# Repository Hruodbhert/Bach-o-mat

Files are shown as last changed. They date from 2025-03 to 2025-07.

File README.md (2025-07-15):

# Bach-o-mat: Electromechanical MIDI Player for Keyboards

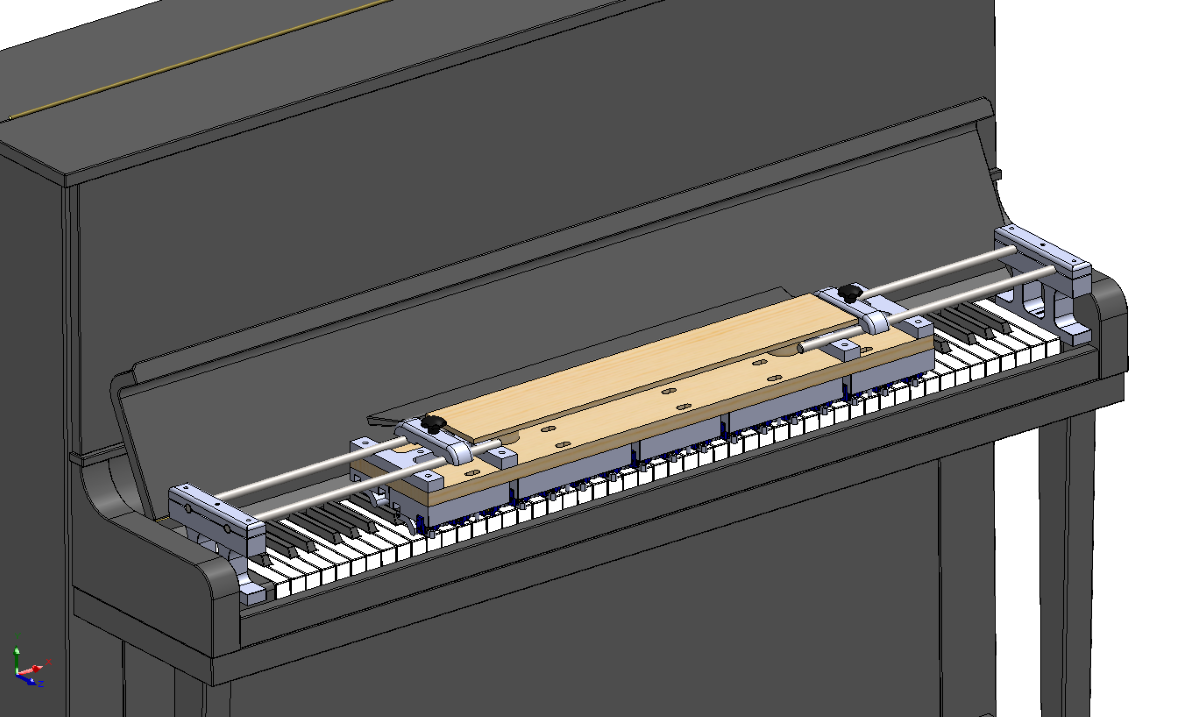
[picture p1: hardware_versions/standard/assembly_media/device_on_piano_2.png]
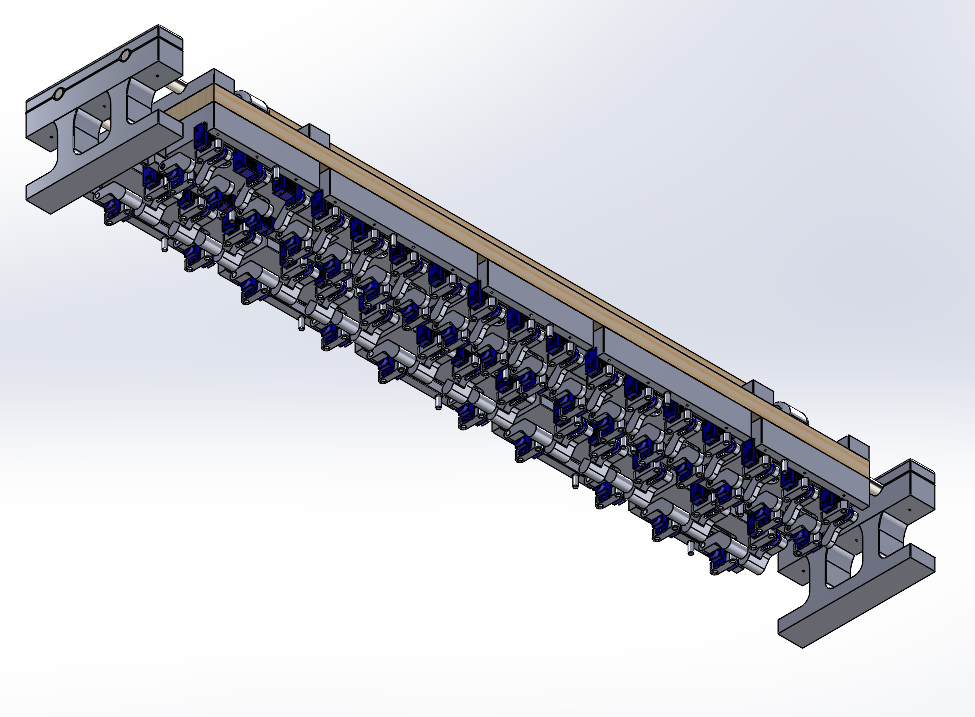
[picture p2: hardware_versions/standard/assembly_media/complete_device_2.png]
|  |  |
| --- | --- |

**Bach-o-mat** is an open-source electromechanical device designed to play **pipe organs**, but it can also be used on any **keyboard instrument**. It operates using **Arduino and micro servomotors**, allowing it to play music by interfacing with a **MIDI control device**.

---

## How It Works
A control device (such as a **PC or smartphone**) connects to Bach-o-mat via **USB** (with **Bluetooth support coming soon**) and sends MIDI signals to activate the keyboard's notes.

## Modular and Expandable Design

Originally developed for **58-note keyboards**, a standard commonly used in **pipe organs until the late 19th century**, Bach-o-mat is built on a **modular architecture**:

- Each **octave of keys** is handled by separate mechanical modules.
- Modules can be easily **combined** and **repositioned** to fit keyboards of different sizes and also with **different key widths**.
- **Sliding side supports** can be employed in order to freely match the layout of any keyboard instrument.

---

## Repository Structure

The repository is organized to support **multiple hardware and electronics versions**.

```
Bach-o-mat/
├── hardware_versions/ # Different 3D and 2D mechanical designs
│ ├── standard/
│ ├── optimized/
│ └── ...
├── electronics_versions/ # Different circuit designs and firmware
│ ├── v1/
│ ├── v2/
│ └── ...
├── docs/ # Shared instructions and documentation
├── README.md # This file
└── LICENSE # Open-source license
```

### `hardware_versions/`

This directory contains **alternative mechanical versions** of Bach-o-mat:

- `standard/`: Original version for 58-note keyboards, with sliding side supports and a horizontal depth of 16 cm
- `optimized/`: 58-notes keyboard version, with fixed supports and an optimized horizontal depth of 11.5 cm

Each subfolder includes:
- **3D models** for 3D printing
- **2D design files** for laser cutting and CNC machining
- Assembly diagrams and media
- A local `README.md` describing that version

### `electronics_versions/`

This directory contains **electronics and firmware variants**, each matching a different design approach:

- `v1/`: Only USB-MIDI interface, with 1 Arduino Micro as master and 5 Arduino Nano as servo controllers
- `v2/`: USB-MIDI and BLE-MIDI interface, with 1 Arduino Nano 33 IoT as master, 1 Arduino Micro for USB-MIDI interface and 5 PCA9685 modules as servo controllers

Each subfolder includes:
- Circuit schematics and wiring diagrams
- Arduino code and configuration files
- Python code of the calibration program
- A local `README.md` with build and upload instructions

---

## Getting Started

1. Browse available versions in [`hardware_versions/`](hardware_versions/) and [`electronics_versions/`](electronics_versions/)
2. Select the combination that fits your needs
3. Follow the `README.md` inside the chosen folders for detailed instructions
4. Assemble, upload firmware, and connect your MIDI control source
5. Enjoy automated keyboard music!

---

## Demonstration

A video demonstration of Bach-o-mat in action is available:

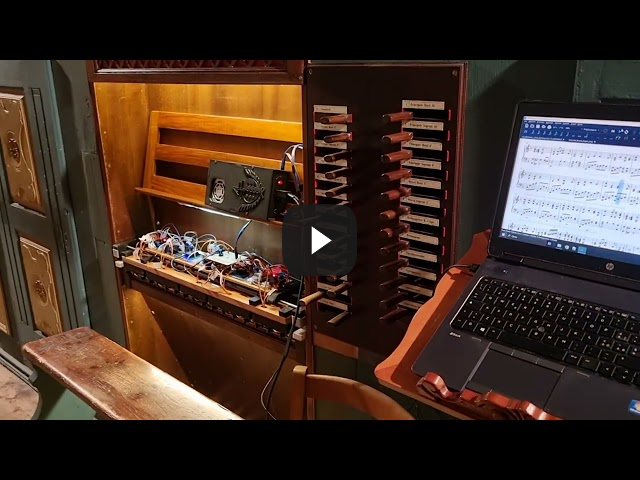
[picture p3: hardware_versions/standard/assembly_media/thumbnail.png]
Setup on Organ Playing (https://youtu.be/sfZ5kHSBi4M?si=CWz8P8_79pBXwW5q)


---

## Future Improvements

- **Expanded keyboard support** for even larger instruments
- **Optimized motor response** for improved playability

---

## License

Bach-o-mat is released under the **GNU General Public License**, making it freely available for modification and use. If you improve the project, consider contributing your modifications back to the community.

---

For any inquiries or contributions, please open an **Issue** or submit a **Pull Request**.

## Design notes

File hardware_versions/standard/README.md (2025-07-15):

# Hardware - Version Standard - 58-Key Modular Design

This is the **original mechanical version** of the Bach-o-mat, designed for **58-key pipe organ-style keyboards**.

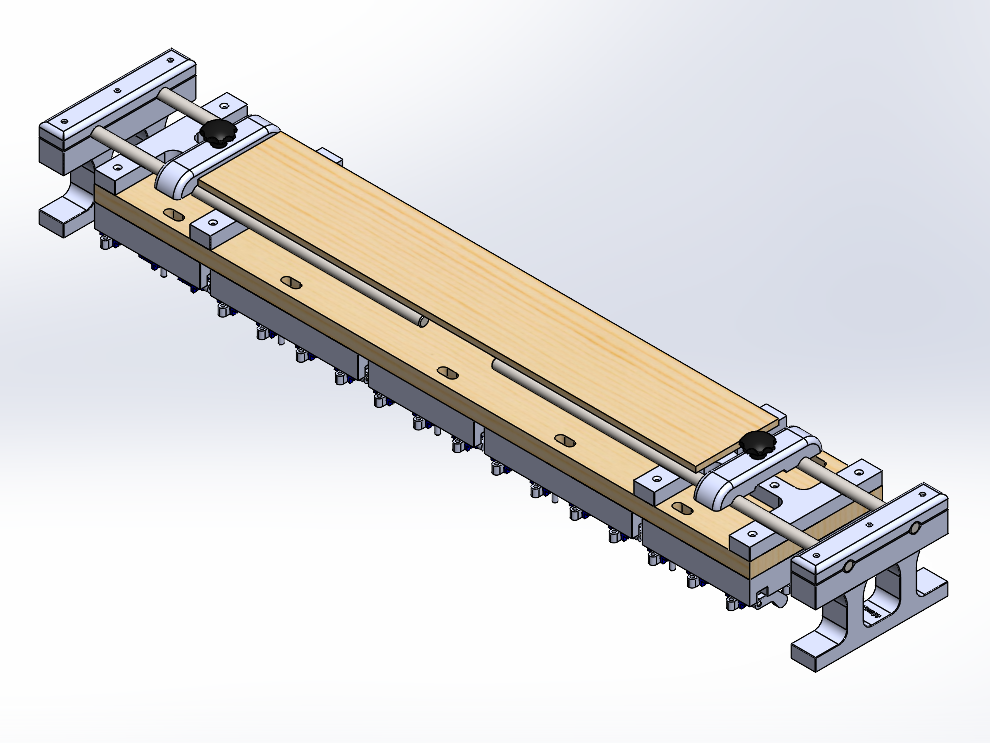
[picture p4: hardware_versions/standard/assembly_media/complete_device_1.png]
 

---

## Table of Contents

1. [Key Features](#key-features)  
2. [Assembly Overview](#assembly-overview)
3. [Compatibility](#compatibility)  
4. [Folder Contents](#folder-contents)
5. [Reference Images](#reference-images)  
6. [License](#license)

---

## Key Features

- Supports **58 keys**
- **Modular structure**: Separate modules for each octave of natural and accidental keys
- **Adjustable horizontal spacing** for compatibility with various key widths from ... mm to ... mm
- **Sliding support bars** for flexible placement across different instruments
- Designed for **FDM 3D printing** and **laser cutting**

---

## Assembly Overview

Each octave consists of:
- A **natural keys module** (white keys)
- An **accidental keys module** (black keys)

For both natural keys and accidental keys modules there is a shorter model for the last octave which has only 10 notes.

These modules can be **replicated and aligned** to form the full 58-key span.

The device rests on two **side support bars**, which:
- Slide to match the keyboard width
- Allow for **non-invasive mounting** (no screws or adhesives required)

The servos are housed in a base layer and press the keys from above using improved 3D printed mechanical arms.

Here below you can find some exploded views for a better understanding of the assembly process.

| Description | Picture |
|---|---|
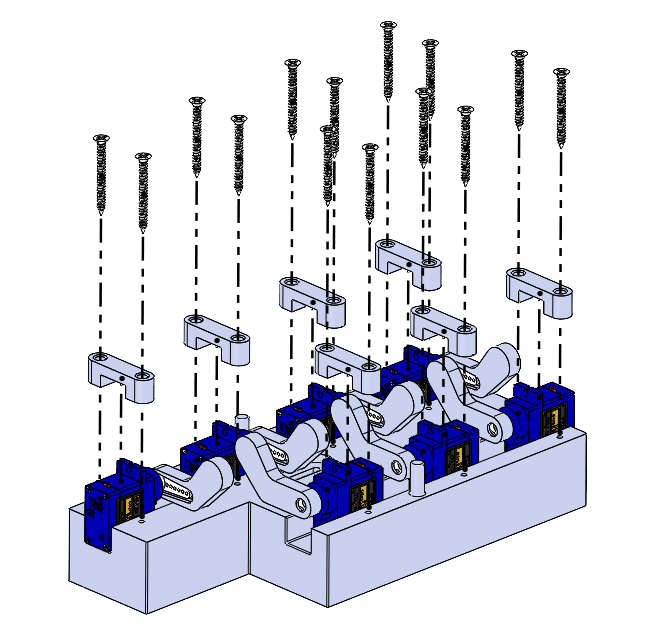
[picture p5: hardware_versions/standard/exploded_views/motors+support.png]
|Motors on the support  ||
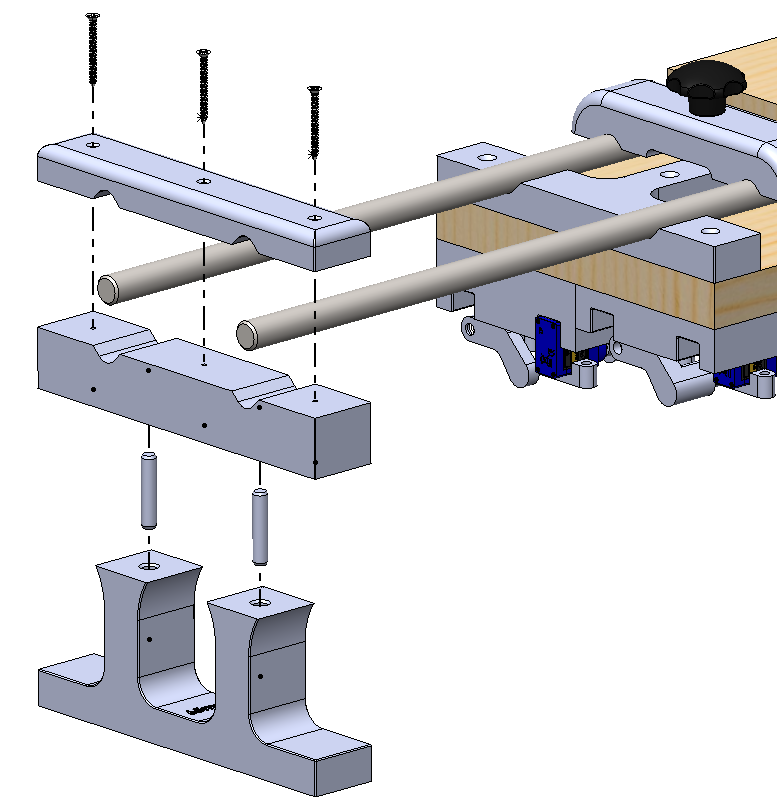
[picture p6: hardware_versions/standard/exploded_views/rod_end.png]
|Rod end ||
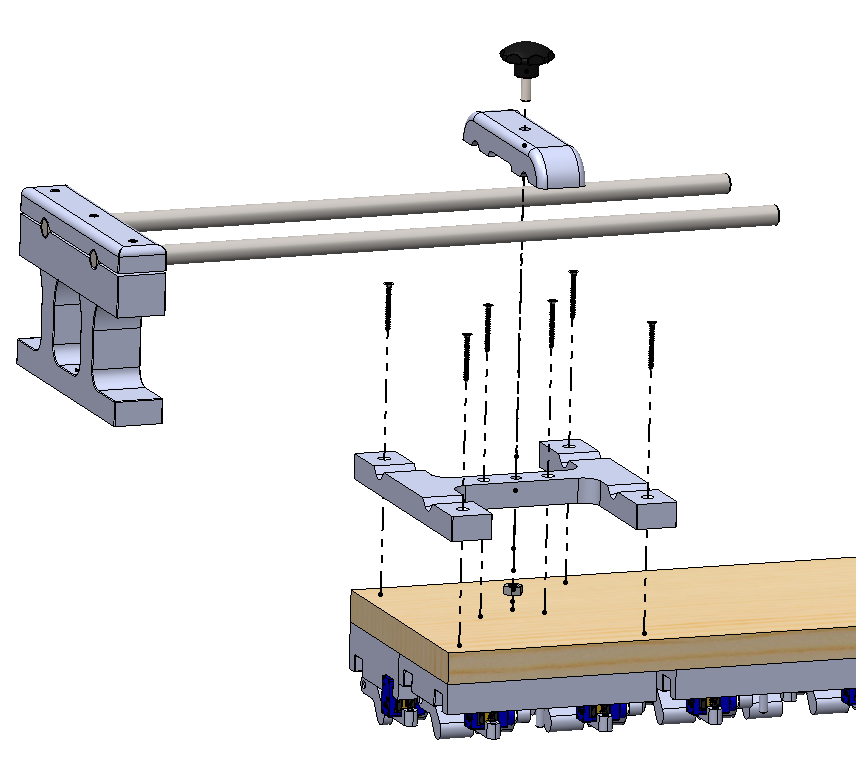
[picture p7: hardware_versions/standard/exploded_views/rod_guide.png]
|Rod guide ||
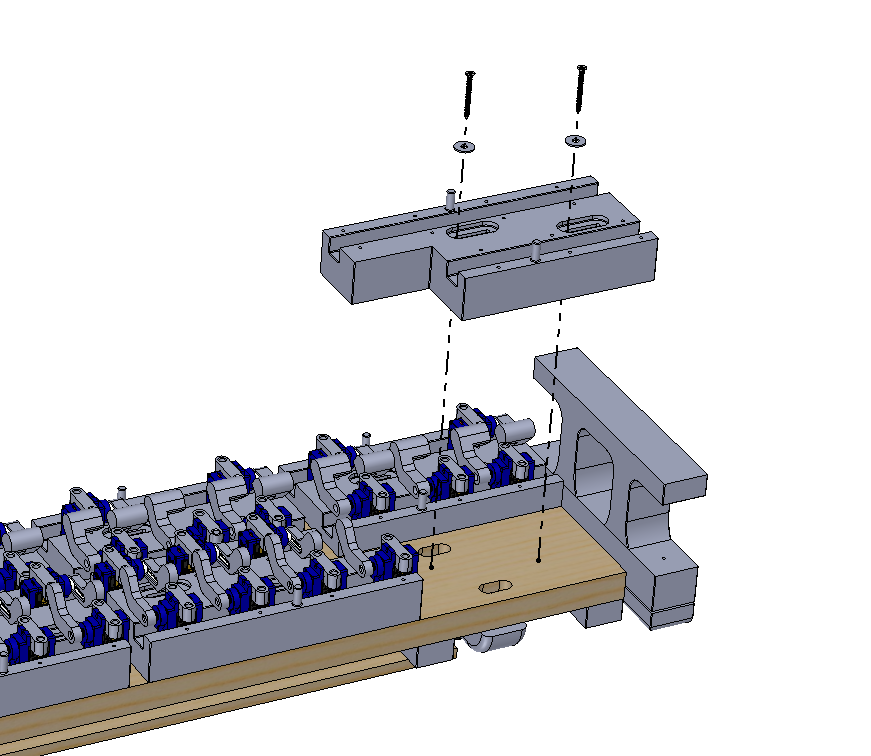
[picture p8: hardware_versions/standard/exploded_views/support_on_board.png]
|Support on board ||

---

## Compatibility

Thanks to the adaptibility of its supports this version is intended for being carried in different places and used to play a wide range of disparate keyboard instruments.<br>
The 3D printable modules are designed to be compatible with almost any keyboard, both historical and commercial, leaving just the duty to pay attention to where to screw them. They should also fit well with quite any commercial microservo available nowadays.<br>
The only non-standard components are the arms of the servos, which may change quite a lot among different models and brands. The 3D printable files provided have therefore a proper external shape, but it might be necessary to change the socket for the servo arm.

---

## Folder Contents

```
standard/
├── 3D_models/ # STEP files for all printed parts
├── 2D_designs/ # DXF files for laser-cut components
├── assembly_media/ # Images and diagrams
├── exploded_views/ # Assembly 3D schemes
└── README.md # This file
```

---

## Reference Images

| Description | Picture |
|---|---|
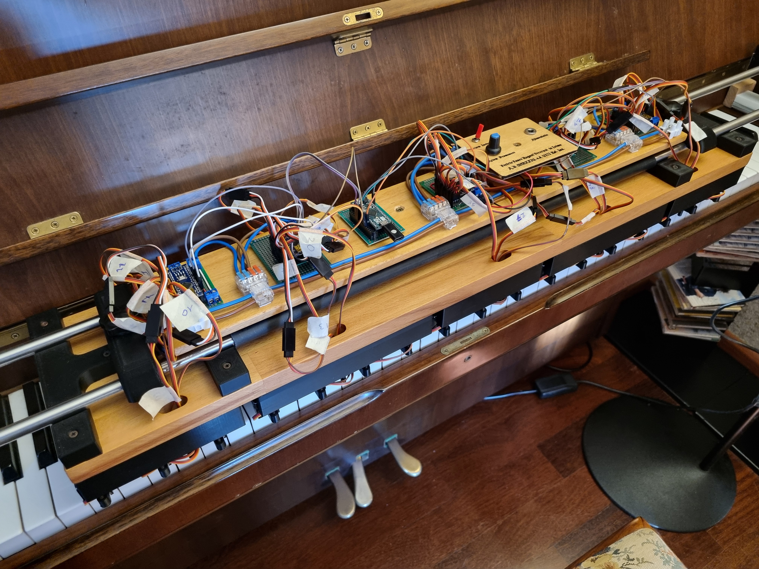
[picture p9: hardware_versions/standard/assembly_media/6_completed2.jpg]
| Assembled Device on Piano  |  |
| Assembled Device on Organ  |  |
| Full Module View |  |

---

## License

Bach-o-mat is released under the **GNU General Public License**, making it freely available for modification and use. If you improve the project, consider contributing your modifications back to the community.

---

For full documentation and software, return to the [main README](../../README.md).

For any inquiries or contributions, please open an **Issue** or submit a **Pull Request**.

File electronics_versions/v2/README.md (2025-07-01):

# Electronics - Version 2 - MIDI-USB and MIDI-BLE

This is an improved version of Bach-o-mat's electronics and firmware,
which allows a **BLE-MIDI connection** to the automaton and adds a **display** and an **encoder** for an easier and PC-less calibration procedure.

# Coming soon!
We are testing it right now, it will be uploaded as soon as possible.

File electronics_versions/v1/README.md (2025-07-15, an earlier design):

# Electronics - Version 1 - MIDI-USB device

This is the first developed version of Bach-o-mat's electronics and firmware, which allows a USB-MIDI connection to the automaton and performs the calibration procedure through a PC.

In terms of microcontrolers here we use

- **Master**: 1x Arduino Micro, which receives MIDI events over USB and routes them to the Nano boards.  
- **Slaves**: 5× Arduino Nano, each controlling 12 servos (one octave of notes).

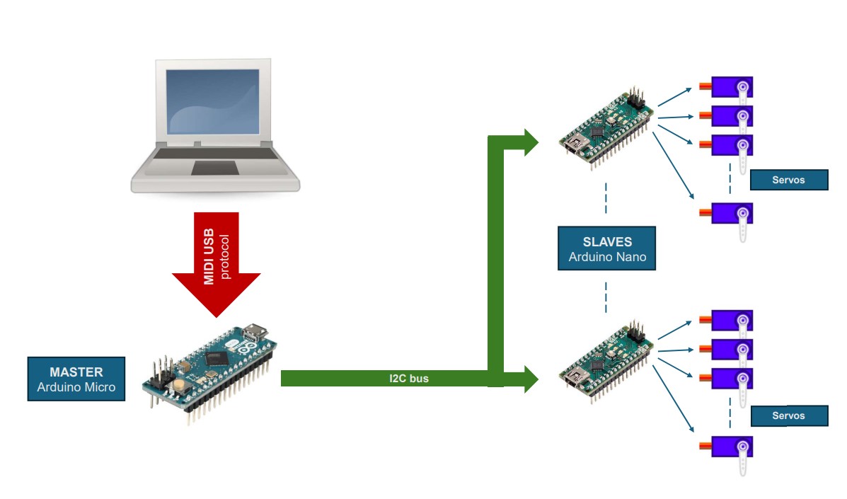
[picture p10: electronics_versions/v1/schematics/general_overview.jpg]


---

## Table of Contents

1. [Hardware Requirements](#hardware-requirements)  
2. [Schematic & Wiring](#schematic--wiring)  
3. [Software Requirements](#software-requirements)  
4. [Usage](#usage)  
5. [Calibration Mode](#calibration-mode)  
6. [Folder Contents](#folder-contents)
7. [License](#license)  

---

## Hardware Requirements

- 1× **Arduino Micro**  
- 5× **Arduino Nano**  
- 60× servos (12 per Nano)  
- Common I²C bus (SDA/SCL) wiring  
- 5 V power supply capable of driving all servos  
- Push-button or switch to Arduino Micro pin 8 (calibration/play mode)  
- Wires, resistors, prototyping board or custom PCB  

---

## Schematic & Wiring

1. **Arduino Micro**  
   - Pin 8 → calibration mode switch  
   - Built‐in LED → mode indicator
   - USB → PC MIDI‐USB
   - SDA, SCL → shared I²C bus to all Nanos

2. **Each Arduino Nano**  
   - A0 (analog) → calibration mode detect  
   - Digital pins 2…13 → servo signal lines (one per note, in total 12 servos (one octave of notes) per Nano)  
   - SDA, SCL → shared I²C bus  
   - 5 V and GND → common power rails  

> **Note:** Assign each Nano a distinct I²C address equal to `OFFSET_INDIRIZZI + INDIRIZZO_MANO`, where `INDIRIZZO_MANO` = 0…4.

Here below you can see the wiring diagram of each Arduino Nano.

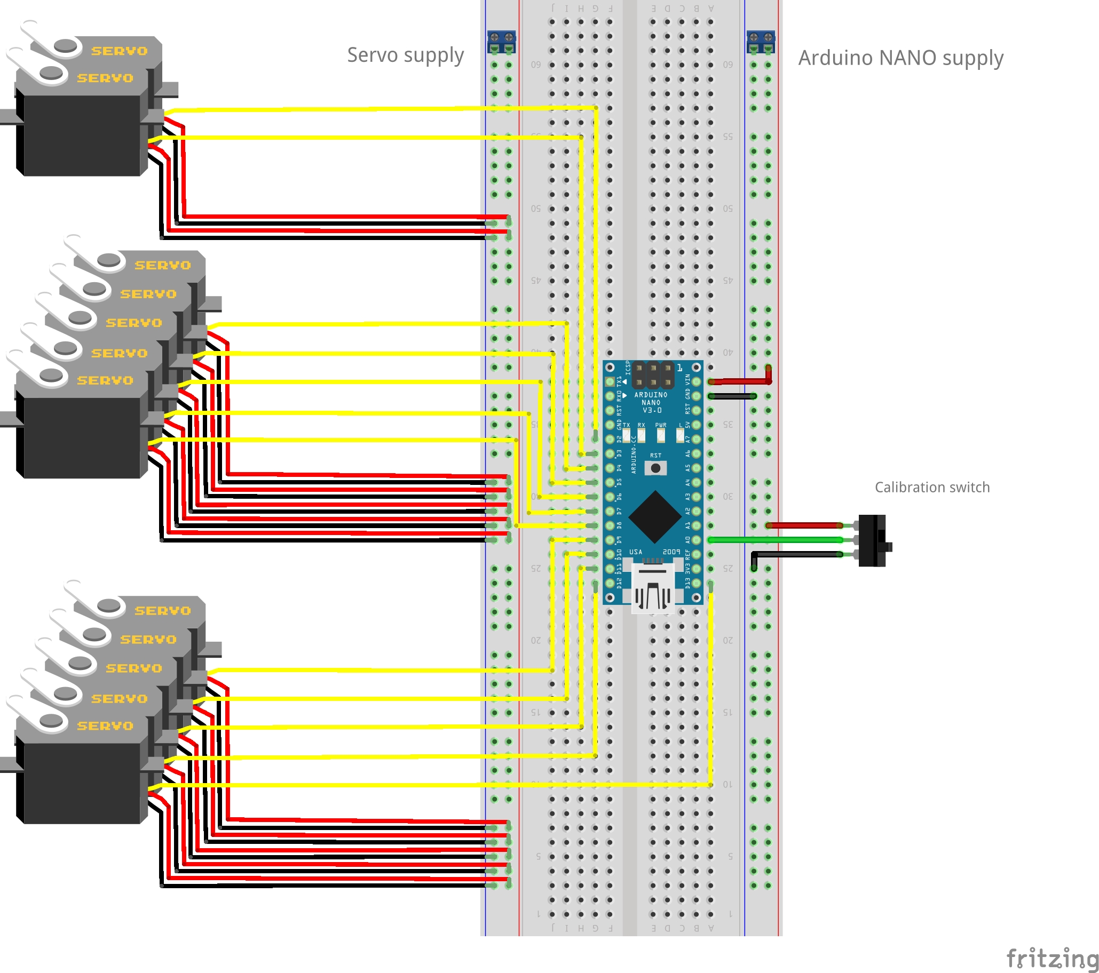
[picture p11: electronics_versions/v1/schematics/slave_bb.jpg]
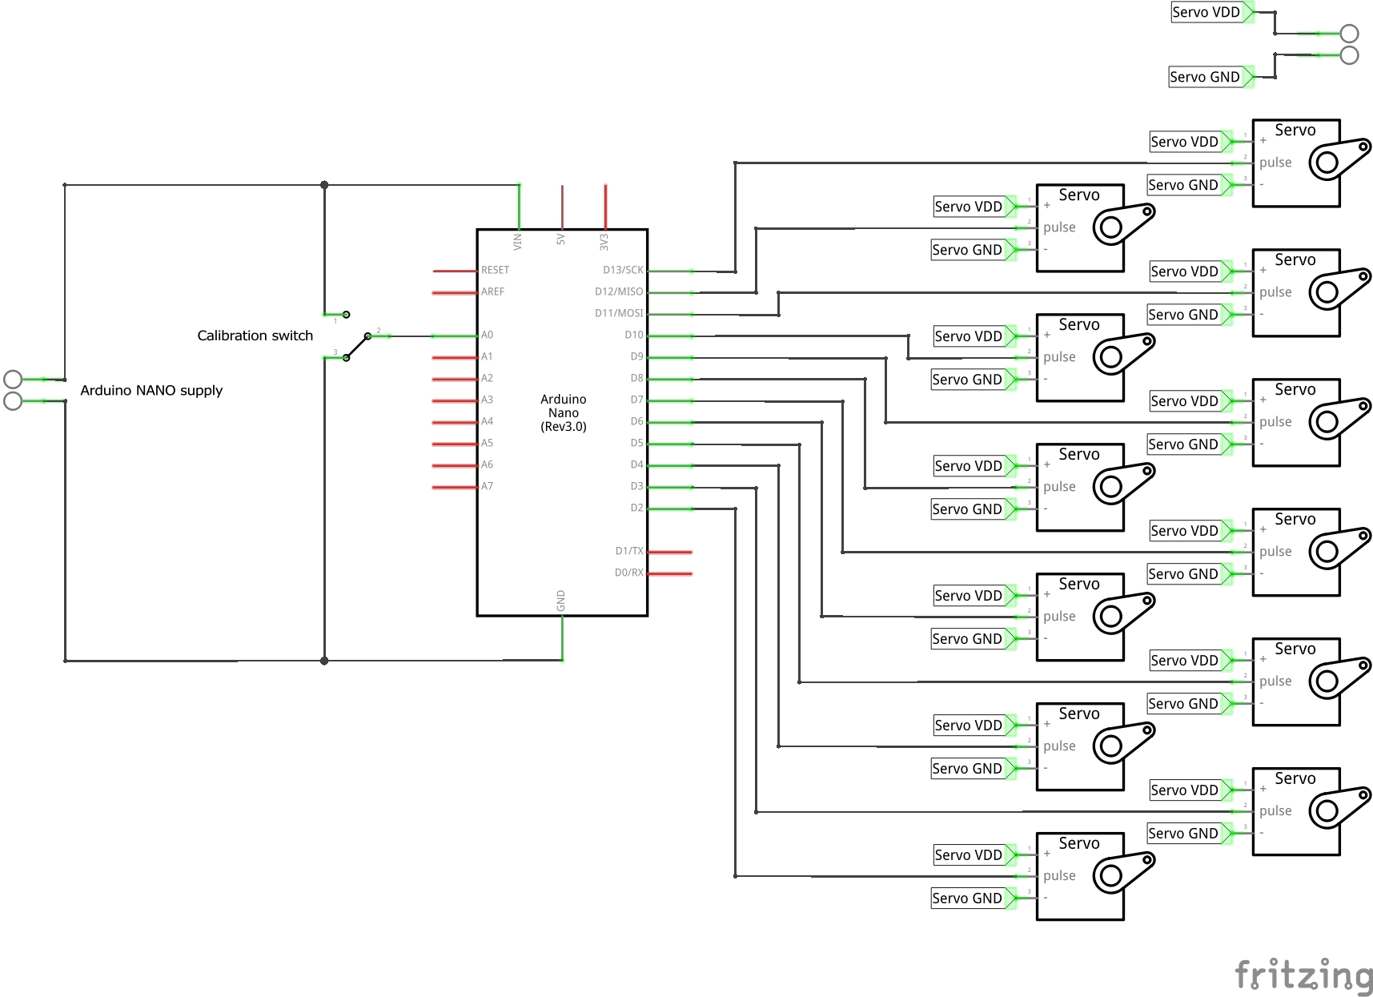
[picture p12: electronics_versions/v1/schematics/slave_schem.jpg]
 

### Tips
Servos consume some hundreds of mA each while working, so when multiple notes are pushed/realeased the total consumption can easily reach ~10A for some instants.
Use a proper power supply and pay attention in cable diameters in order not to have voltage faults.

---

## Software Requirements

- Libraries:
  - `MIDIUSB.h`  
  - `Wire.h`  
  - `Servo.h`  
  - `EEPROM.h`  

---

# Usage

## Play mode
- Ensure the calibration switch is LOW (play mode); the Micro’s LED will be OFF.
- Connect the Arduino Micro to your PC via USB and the entire system to a 5V voltage source.
- In your MIDI software, select "Arduino Micro" as MIDI output.
- Play notes: the Micro reads MIDI Note On/Off and sends I²C commands to the Nanos.

## Calibration Mode
The system enters in the calibration mode when, **at its startup**, the calibration switch is HIGH.
Arduino Micro listens on Serial @9600 bps and forwards setup commands over I²C.
Arduino Nano enters setup to map servo angles and save them to EEPROM.

### Workflow
Send 3–4 byte packets over Serial to the Micro:
- operation byte (1=push/release, 2=set angles, 3=set+save)
- servo_num (0... TOT_SERVO-1)
- data_1 (off‐angle)
- [data_2] (delta_angle, only for operation byte≠1)

This operations can be done easily by using the [calibration_GUI_v1.py](./codes/calibration_GUI_v1.py) provided.

Exit calibration mode by switching to LOW the calibration switch: Nanos will load saved angles and begin normal play.

## Folder Contents

```
v1/
├── calibration_files/ # examples of files to be loaded to calibration_GUI_v1.py
├── codes/ # .ino codes for both master and slave boards and calibration_GUI_v1.py file
├── schematics/ # Wiring diagrams
└── README.md # This file
```

## License

Bach-o-mat is released under the **GNU General Public License**, making it freely available for modification and use. If you improve the project, consider contributing your modifications back to the community.

---

For full documentation and software, return to the [main README](../../README.md).

For any inquiries or contributions, please open an **Issue** or submit a **Pull Request**.

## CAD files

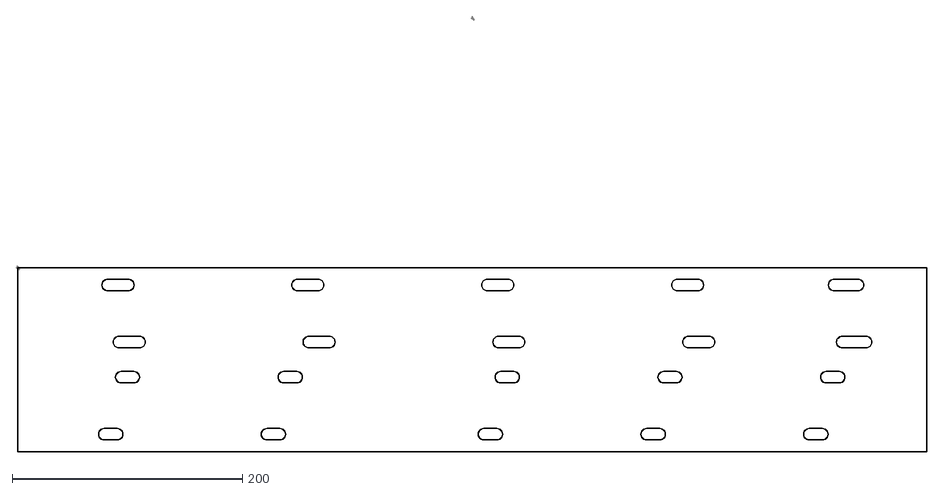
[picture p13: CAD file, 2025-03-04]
hardware_versions/standard/2D_designs/board_holes_map.DXF
790.9 x 378.3

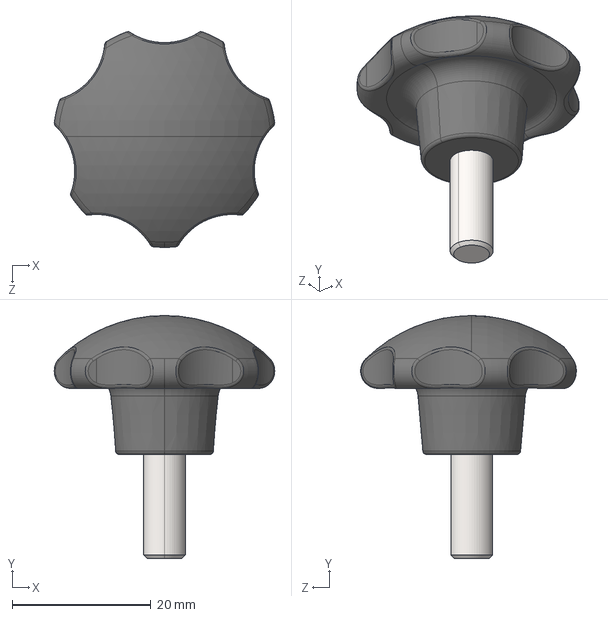
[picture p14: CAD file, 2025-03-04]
hardware_versions/standard/3D_models/Star Knob M6 Male_(Default).STEP
31.8 x 35.0 x 31.1 mm

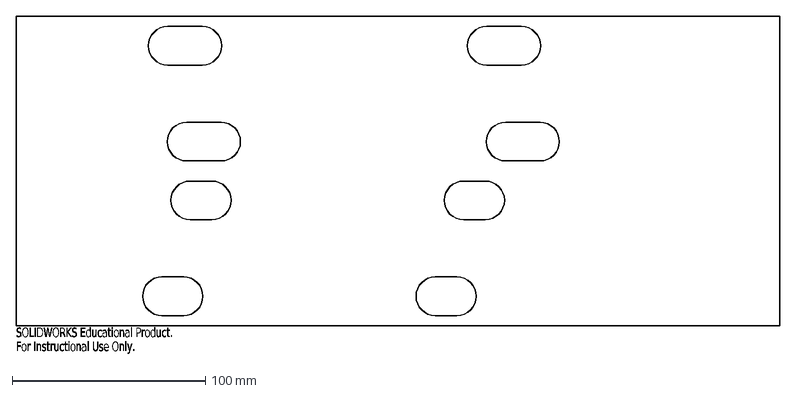
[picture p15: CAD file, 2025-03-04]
hardware_versions/standard/2D_designs/board_holes_map_left.DXF
SOLIDWORKS Educational Product.
For Instructional Use Only.

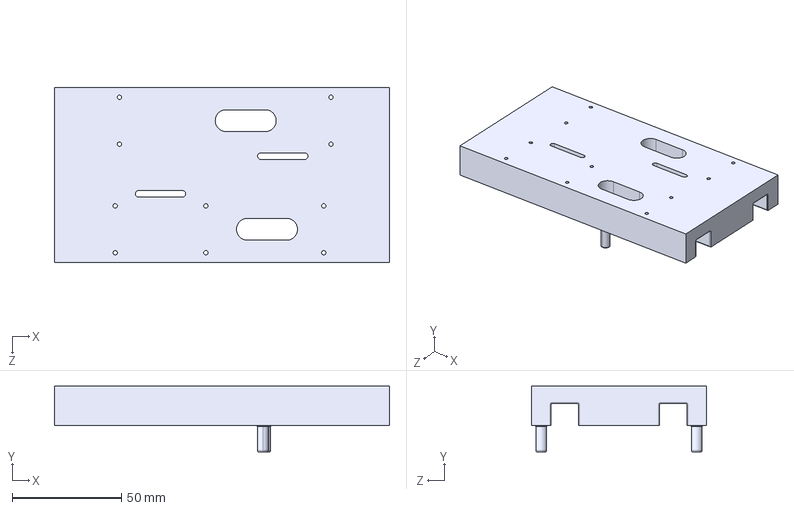
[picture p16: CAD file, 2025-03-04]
hardware_versions/standard/3D_models/motor_support_accidentals.STEP
153.0 x 30.0 x 80.0 mm

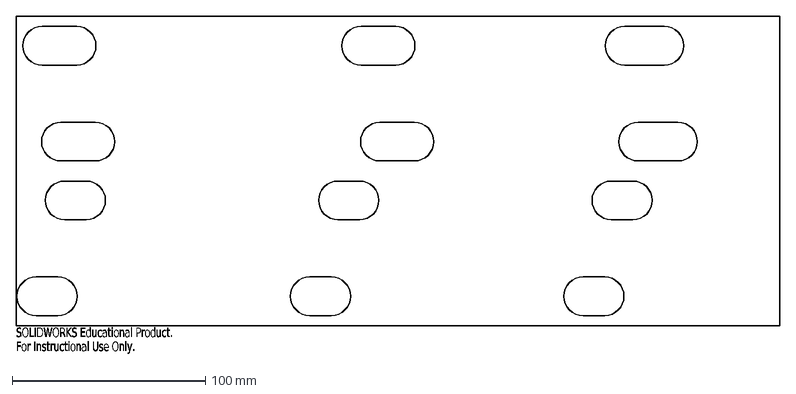
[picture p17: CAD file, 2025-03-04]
hardware_versions/standard/2D_designs/board_holes_map_right.DXF
SOLIDWORKS Educational Product.
For Instructional Use Only.

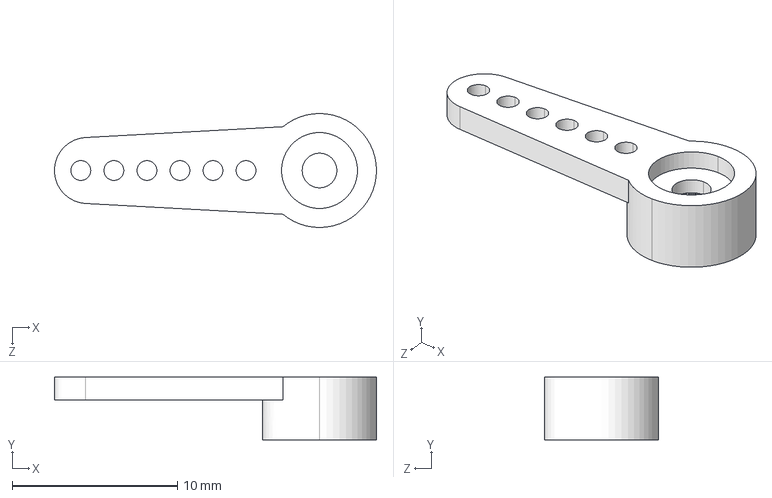
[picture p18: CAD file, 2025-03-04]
hardware_versions/standard/3D_models/micro_servo_arm.STEP
19.5 x 3.80 x 6.90 mm

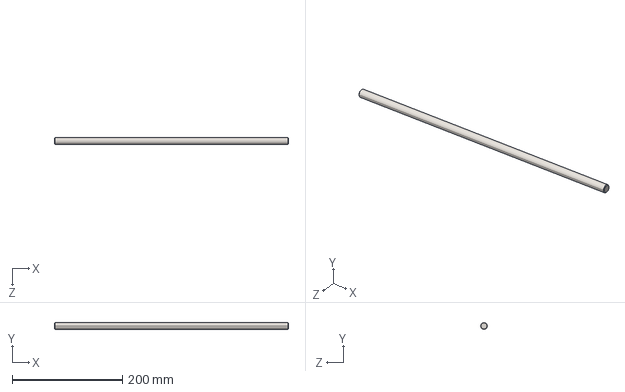
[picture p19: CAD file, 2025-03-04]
hardware_versions/standard/3D_models/rod.STEP
425.0 x 12.0 x 12.0 mm

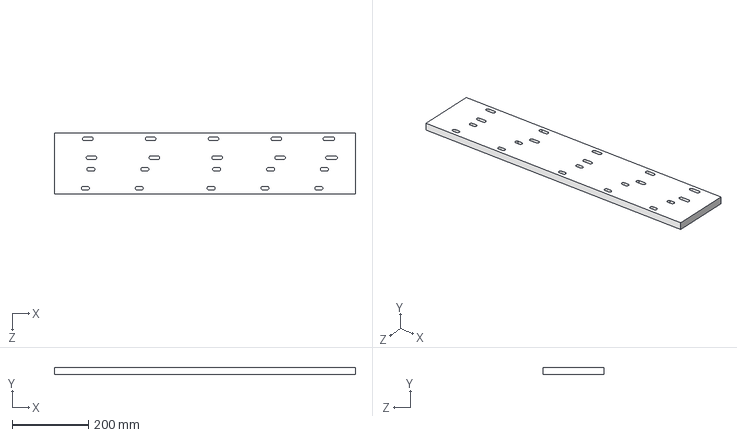
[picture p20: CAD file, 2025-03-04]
hardware_versions/standard/3D_models/wooden_board.STEP
790.0 x 19.0 x 160.0 mm

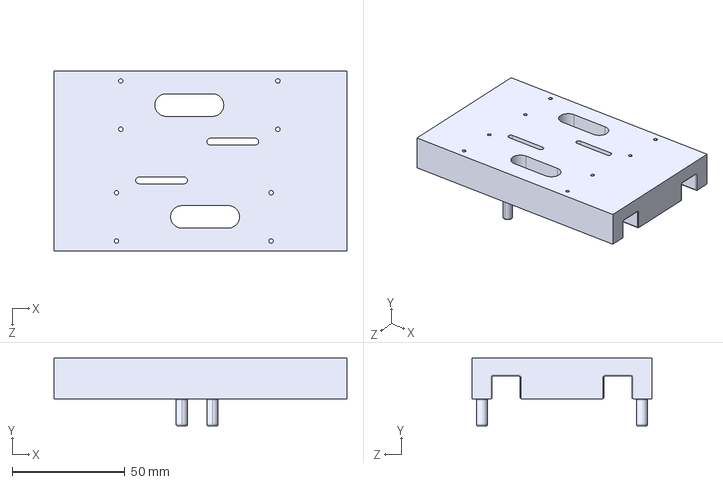
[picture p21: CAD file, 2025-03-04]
hardware_versions/standard/3D_models/motor_support_accidentals_end.STEP
130.0 x 30.0 x 80.0 mm

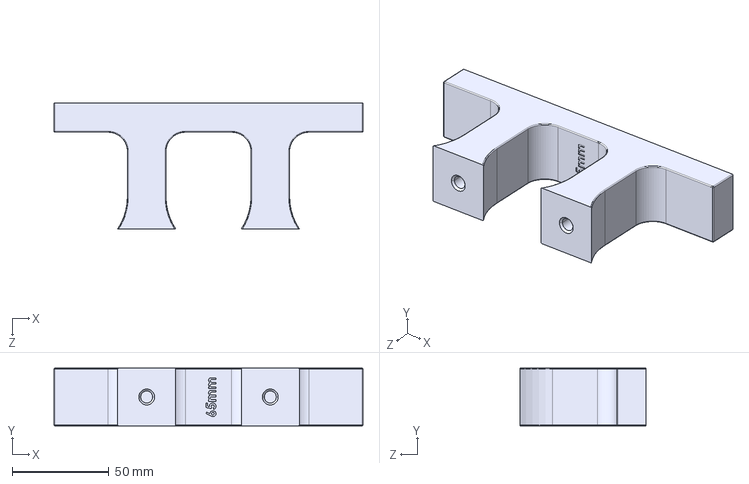
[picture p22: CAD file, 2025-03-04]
hardware_versions/standard/3D_models/rod_end_foot.STEP
160.0 x 30.0 x 65.0 mm

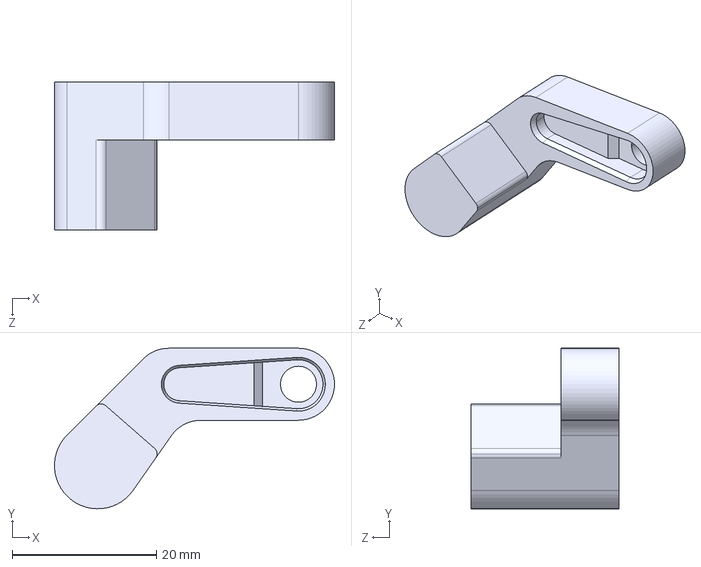
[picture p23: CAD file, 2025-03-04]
hardware_versions/standard/3D_models/finger_accidentals.STEP
38.9 x 22.3 x 20.5 mm

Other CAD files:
hardware_versions/standard/3D_models/COMPLETE_MODEL.STEP
hardware_versions/standard/3D_models/support+motors_naturals_end.STEP
hardware_versions/standard/3D_models/support+motors_naturals.STEP
hardware_versions/standard/3D_models/Star Knob M6 Male.STEP
hardware_versions/standard/3D_models/support+motors_accidentals_end.STEP
hardware_versions/standard/3D_models/motor+finger_naturals.STEP
hardware_versions/standard/3D_models/motor+finger_accidentals.STEP
hardware_versions/standard/3D_models/Screw M3 x 30 for Wood.STEP
hardware_versions/standard/3D_models/finger_naurals.STEP
hardware_versions/standard/3D_models/micro_servo_body.STEP
hardware_versions/standard/3D_models/micro_servo_screw.STEP
hardware_versions/standard/3D_models/motor_bracket.STEP
hardware_versions/standard/3D_models/motor_support_natural.STEP
hardware_versions/standard/3D_models/motor_support_naturals_end.STEP
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

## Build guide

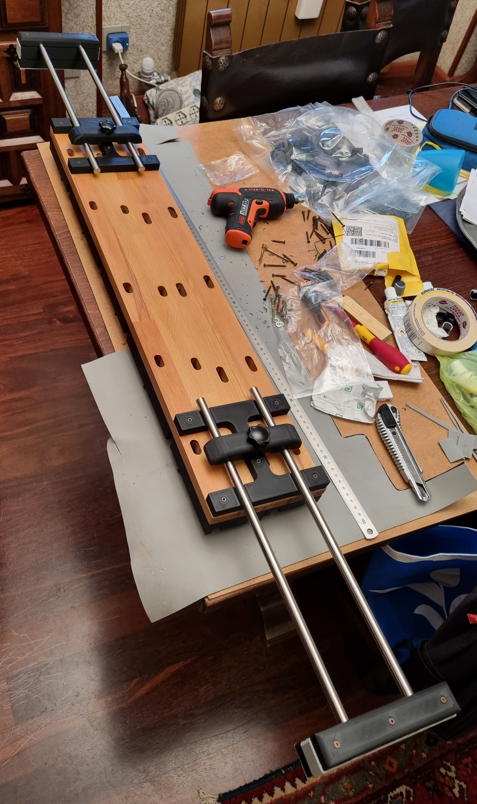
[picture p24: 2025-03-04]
hardware_versions/standard/assembly_media/5_final1.jpg

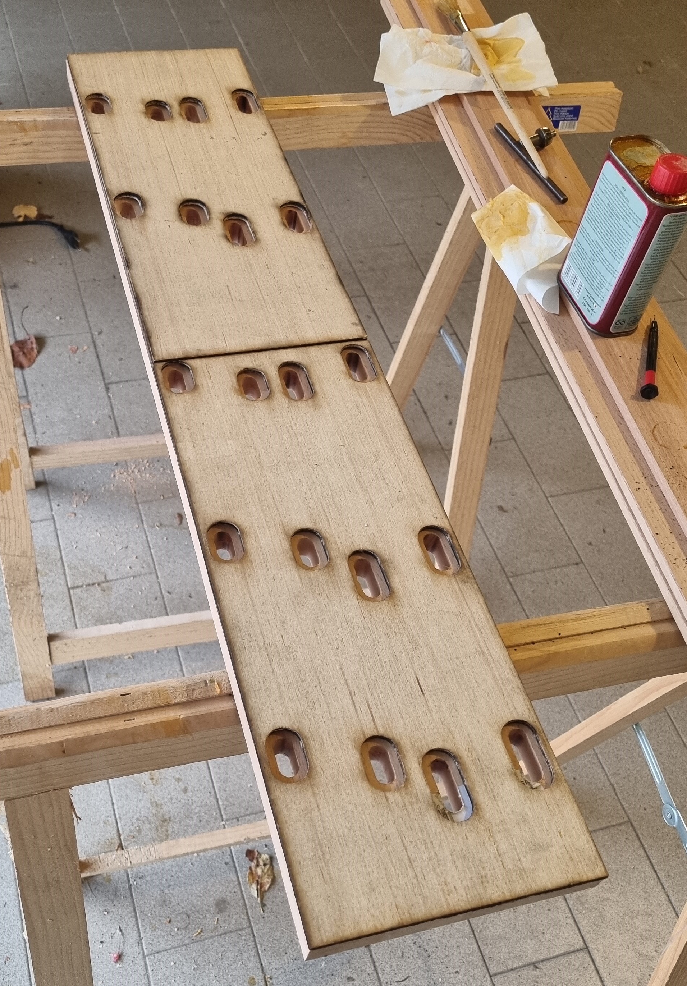
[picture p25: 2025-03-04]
hardware_versions/standard/assembly_media/1_board2.jpg

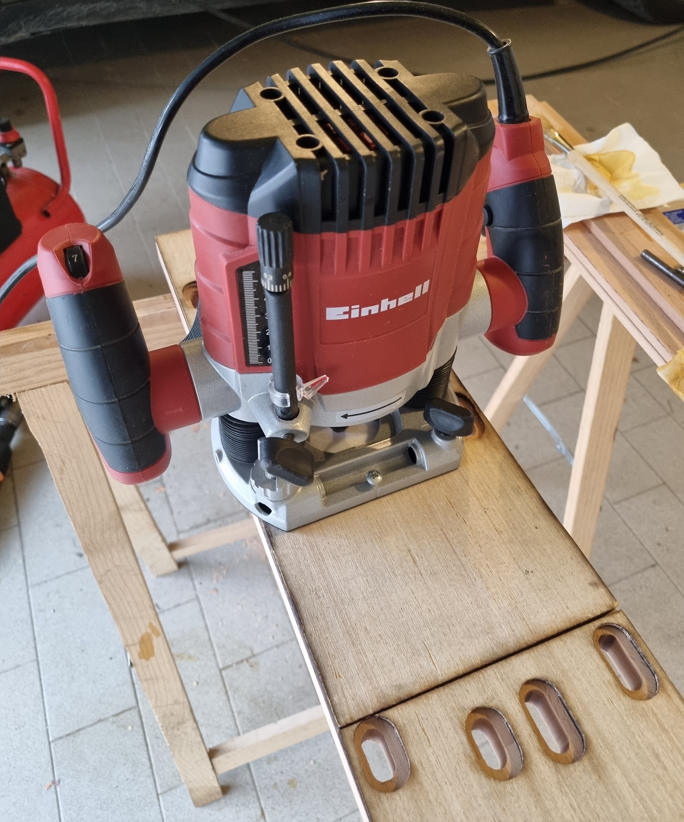
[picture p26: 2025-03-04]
hardware_versions/standard/assembly_media/1_board5.jpg

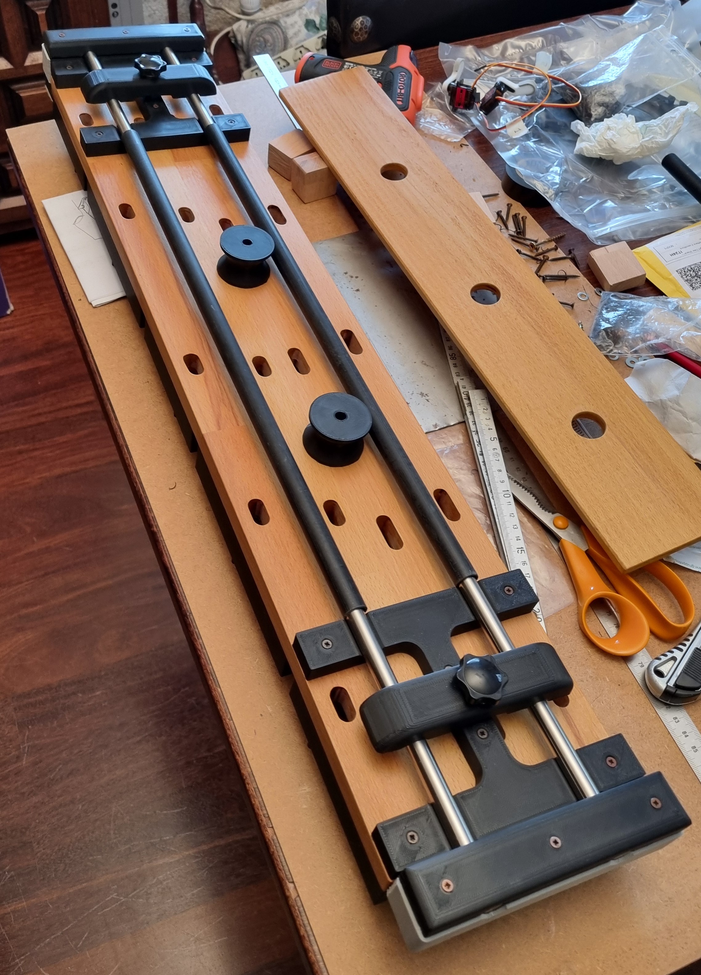
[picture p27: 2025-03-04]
hardware_versions/standard/assembly_media/5_final2.jpg

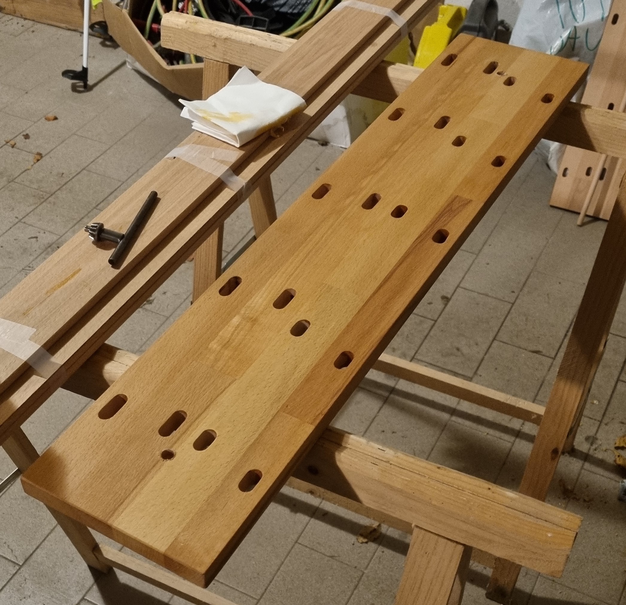
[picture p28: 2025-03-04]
hardware_versions/standard/assembly_media/1_board1.jpg

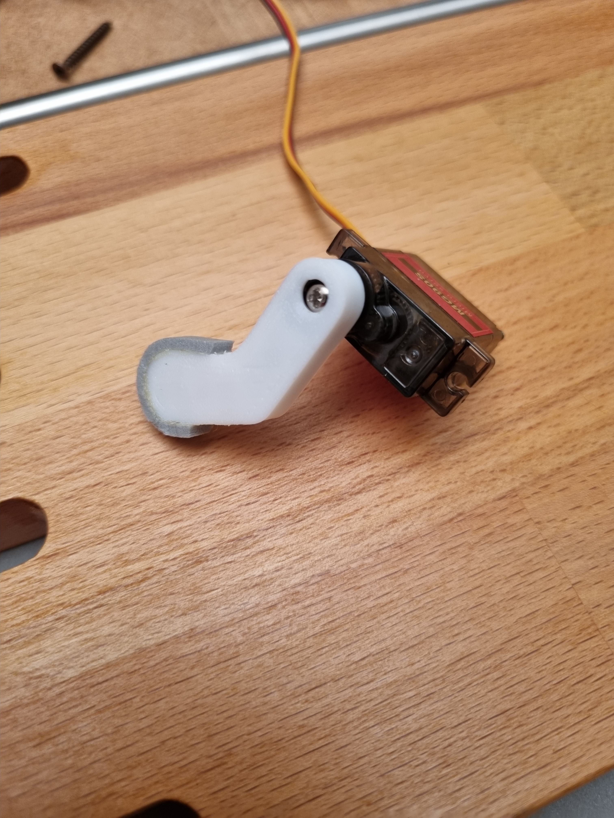
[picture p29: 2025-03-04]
hardware_versions/standard/assembly_media/4_finger2.jpg

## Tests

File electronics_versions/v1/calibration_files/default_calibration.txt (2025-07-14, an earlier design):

145, 40
145, 40
145, 40
145, 40
145, 40
145, 40
145, 40
145, 40
145, 40
145, 40
145, 40
145, 40
145, 40
145, 40
145, 40
145, 40
145, 40
145, 40
145, 40
145, 40
145, 40
145, 40
145, 40
145, 40
145, 40
145, 40
145, 40
145, 40
145, 40
145, 40
145, 40
145, 40
145, 40
145, 40
145, 40
145, 40
145, 40
145, 40
145, 40
145, 40
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

100
5

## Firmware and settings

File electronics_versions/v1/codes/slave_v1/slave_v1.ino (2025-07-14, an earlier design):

/*
 * Slave boards code of Bach-o-mat, firmware version "v1"
 * This code is though to be uploaded on an Arduino Nano board which will receive push/relaese commands from an Arduino Micro board
 * 
 * GitHub repository:
 * https://github.com/Hruodbhert/Bach-o-mat/
 * 
 * Authors: Giulio and Roberto Faure Ragani
 * A.D. 2025
 * 
 */
 
#include <Wire.h>
#include <Servo.h>
#include <EEPROM.h>

#define INDIRIZZO_MANO 4    // I2C address (to be changed from 0 (lowest octave) to 4 (highest octave) in the five different Arduino Nano boards

#define NOTE_PER_MANO 12   // Number of servos controlled by each Arduino Nano board

#define OFFSET_INDIRIZZI 8  // Offset applied to I2C addresses (the first 8 addresses are reserved by I2C standards)

#define SAFE_START_ANGLE 145

#define CALIBRATION_MODE_PIN A0  //Pin for calibration/play mode switch (HIGH=setup, LOW=play)
#define SOGLIA 512 // Threshold for analog to digital conversion (in 0 or 1) (Arduino Nano has a resolution of 10 bits => 1024 values)

Servo dito[NOTE_PER_MANO];

int angle[NOTE_PER_MANO][2];
byte note;
bool state;
bool setup_state[NOTE_PER_MANO];

///////////////////////////////////////////
////////////////SETUP FUNCTIONS
///////////////////////////////////////////

void handle_setup() {
  byte operation = Wire.read();
  byte servo_num = Wire.read();
  byte data_1 = Wire.read();
  byte data_2;
  if (operation != 1) {
    data_2 = Wire.read();
  }
  switch ((int) operation) {
    case 1: // Push/Release
      setup_state[servo_num] = (data_1 == 1);
      push(servo_num, setup_state[servo_num]);
      break;
    case 2: // Set angles
      angle[servo_num][0] = (int)data_1; //  off_angle
      angle[servo_num][1] = (int)(data_1 - data_2); //  on_angle = off_angle - delta_angle
      push(servo_num, setup_state[servo_num]);
      break;
    case 3: // Set and save angles
      // Set
      angle[servo_num][0] = (int)data_1; //  off_angle
      angle[servo_num][1] = (int)(data_1 - data_2); //  on_angle = off_angle - delta_angle
      push(servo_num, setup_state[servo_num]);
      // Save
      // EEPROM organized in this way : [off_angle_0, on_angle_0, off_angle_1, on_angle_1,... off_angle_11, on_angle_11]
      EEPROM.update(2 * servo_num, data_1);
      EEPROM.update(2 * servo_num + 1, data_1 - data_2);
      break;
    default:
      break;
  }
}

///////////////////////////////////////////
////////////////PLAY FUNCTIONS
///////////////////////////////////////////

void push(byte servo_num, bool state) {
  dito[servo_num].write(angle[servo_num][state]);
  return;
}

////////////////////////////

void play() {
  byte c = Wire.read();
  note = c % NOTE_PER_MANO;
  state = !(bool(c / NOTE_PER_MANO));
  push(note, state);
}

////////////////////////////
void get_angles_from_EEPROM() {
  for (int i = 0; i < NOTE_PER_MANO; i++) {
    angle[i][0] = EEPROM.read(2 * i);
    angle[i][1] = EEPROM.read(2 * i + 1);
  }
}
///////////////////////////////////

void setup() {

  //Attach Servos
  //Arduino NANO
  for (int i = 0; i < NOTE_PER_MANO; i++) {
    dito[i].attach(i + 2);
    dito[i].write(SAFE_START_ANGLE);
    setup_state[i] = 0;
  }
  // Get angles from EEPROM
  get_angles_from_EEPROM();

  //CALIBRATION MODE
  if (analogRead(CALIBRATION_MODE_PIN) > SOGLIA) { //CALIBRATION MODE
    Wire.begin(INDIRIZZO_MANO + OFFSET_INDIRIZZI);
    Wire.onReceive(handle_setup);
    while (analogRead(CALIBRATION_MODE_PIN) > SOGLIA) {
      delay(20);
    }
    Wire.end();
    // Get angles from EEPROM
    get_angles_from_EEPROM();
  }
  //END OF CALIBRATION

  //Set Servos OFF
  for (byte i = 0; i < NOTE_PER_MANO; i++) {
    push(i, '\0');
  }

  Wire.begin(INDIRIZZO_MANO + OFFSET_INDIRIZZI);
  Wire.onReceive(play);
}

void loop() {
  delay(5);
}

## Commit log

2025-03-01 First commit - added initial project structure
    [COMPLETE_MODEL.STEP, Screw M3 x 30 for Wood.STEP, Star Knob M6 Male.STEP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]
2025-03-01 Added .step CAD files
    [COMPLETE_MODEL.STEP, Screw M3 x 30 for Wood.STEP, Star Knob M6 Male.STEP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]
2025-03-04 added DXF files and assembly images
    [COMPLETE_MODEL.STEP, Screw M3 x 30 for Wood.STEP, Star Knob M6 Male.STEP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]
2025-03-04 Added images in readme file
    [COMPLETE_MODEL.STEP, Screw M3 x 30 for Wood.STEP, Star Knob M6 Male.STEP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]
2025-06-30 Clean up
    [COMPLETE_MODEL.STEP, Screw M3 x 30 for Wood.STEP, Star Knob M6 Male.STEP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]
2025-06-30 Media added to standard hardware
    [COMPLETE_MODEL.STEP, Screw M3 x 30 for Wood.STEP, Star Knob M6 Male.STEP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]
2025-06-30 Update to standard hardware README
    [COMPLETE_MODEL.STEP, Screw M3 x 30 for Wood.STEP, Star Knob M6 Male.STEP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]
2025-07-14 Changed schematics v1
2025-07-14 Updated README and schematics electronics v1
